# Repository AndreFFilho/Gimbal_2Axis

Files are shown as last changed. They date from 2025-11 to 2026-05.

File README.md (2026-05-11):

# 📷 IoT 2-Axis Gimbal Stabilization System (ESP32)






<p align="center">
  Gimbal Stabilization Demo
</p>

This repository contains the firmware for the embedded system and the supervisory interface for a **2-Axis Gimbal** (Pitch and Roll). The project was developed with a focus on **Real-Time Automation** and **Embedded Systems**, using the **ESP32** microcontroller.

The system combines **Field Oriented Control** (FOC), Sensor Fusion via **Kalman Filter**, and secure IoT communication over **MQTT**.

---

## 📂 Repository Structure

The repository is organized in a modular way to facilitate maintenance and testing:

```text
├── assets/              # PCB Design and Schematics
├── hardware/            # Gerber Files (PCB Manufacturing)
├── components/          # External Libraries (I2Cdev, MPU6050)
├── main/
│   ├── BATERIA/         # ADC Reading and Moving Average Filter
│   ├── BOTAO/           # Interrupt Handling and Debounce
│   ├── BUFFER/          # Circular Buffer (Producer-Consumer)
│   ├── LOGGER/          # Hybrid Logging System (Serial/MQTT)
│   ├── MPU6050/         # Driver Abstraction and Kalman Filter
│   ├── PID/             # Control Algorithm and SimpleFOC
│   ├── WIFI_MQTT/       # Connection Management and IoT Protocol
│   ├── main.c           # System Initialization and Task Orchestration
│   └── mainGlobals.h    # Mutexes, Semaphores and Global Variables
├── .devcontainer/       # Docker Environment Configuration
├── Interface/           # Flet Interface (Python)
└── CMakeLists.txt       # Build Configuration
```

---

## 🌟 Firmware Features

* **Real-Time Control:** Deterministic **PID loop** running at **200Hz (5ms)**, prioritized via FreeRTOS.
* **SimpleFOC:** Vector Control (SVPWM) for Brushless motors (BLDC), ensuring smooth motion.
* **Sensor Fusion:** Implemented via **Kalman Filter**.
* **IoT & MQTT:** Telemetry (Angle/Battery) and remote setpoint reception over MQTT with TLS support.
* **Multitasking:** Architecture based on Tasks, Queues, Mutexes and Semaphores to prevent *race conditions*.
* **Reproducible Environment:** Native support for **Docker (Dev Containers)**.

## 🧠 Technical Challenges & Control Strategy

**Overcoming Sensor Latency:**
Initially, the system relied on the MPU6050’s internal Digital Motion Processor (DMP) to obtain pitch and roll angles. However, the DMP introduced processing delays that restricted the control bandwidth. This latency prevented us from increasing the PID gains without pushing the system into instability, resulting in a sluggish motor response. 

To solve this, we bypassed the DMP entirely. By implementing a custom **Kalman Filter** directly on the raw accelerometer and gyroscope data, we drastically reduced latency and increased the sampling rate. This software solution allowed for higher PID gains, yielding a much faster and more aggressive system response.

**Mechanical Resonance & Structural Flexibility:**
During high-frequency operation, we identified a mechanical limitation. The 3D-printed ABS arms exhibited structural flexibility, essentially acting as a mass-spring (second-order) system. When the motors accelerated rapidly to correct large errors, the arms vibrated. While the control loop was robust enough to stabilize the gimbal, this mechanical resonance lowered the overall margin of stability. This highlighted the crucial relationship between rigid mechanical design and high-frequency control loops.

---

## 🛠️ Hardware and Pinout

The firmware is configured with the **following** pin assignment for the ESP32 (DevKit V1):

* **Microcontroller:** ESP32 (DevKit V1 or similar).
* **Sensors:** MPU6050 (Accelerometer + Gyroscope).
* **Actuators:** 2x Brushless Motors (Gimbal Motors) + 2x Drivers (SimpleFOC Mini v1.0).
* **Power Supply:** Li-Ion Battery 2S (7.4V).
* **Converters:** Buck Mini360 and Boost XL6009.
* **Connections (Default Pinout):**

| Component | ESP32 Pin | Function | Details |
| :--- | :--- | :--- | :--- |
| **I2C Bus** | GPIO 21 (SDA), 22 (SCL) | Communication | MPU6050 Sensor (Address 0x68) |
| **Pitch Motor** | GPIO 19, 18, 17 | PWM (Phases A/B/C) | SimpleFOC Mini v1.0 |
| **Roll Motor** | GPIO 25, 26, 27 | PWM (Phases A/B/C) | SimpleFOC Mini v1.0 |
| **Motor Enable**| GPIO 4 (Pitch), 14 (Roll)| Digital Out | Driver Enable Signal |
| **Battery** | GPIO 34 | Analog In (ADC) | Voltage Divider (2S Monitoring) |
| **Button** | GPIO 33 | Digital In (ISR) | Physical Button with Pull-up |
| **Status LED** | GPIO 32 | Digital Out | Battery Indicator |

### 🖨️ Printed Circuit Board (PCB)

A dedicated PCB was developed to ensure **mechanical robustness** for the Gimbal assembly. The **design includes** onboard voltage regulation and modular connectors.

| Top View | Bottom View |
| :---: | :---: |
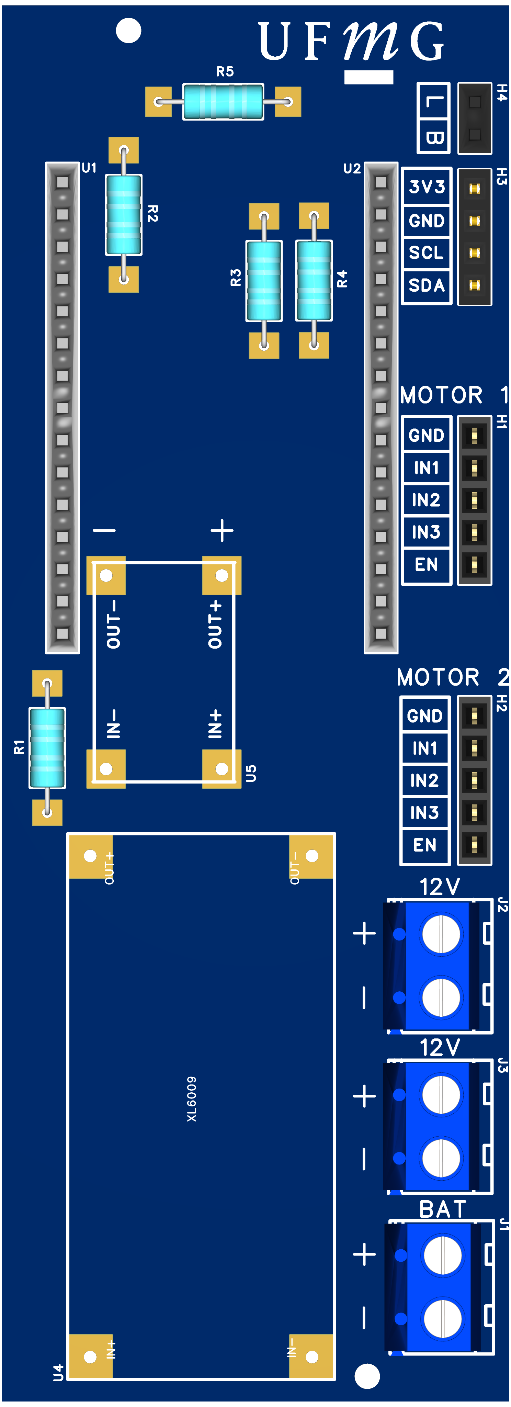
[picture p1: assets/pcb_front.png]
Front View PCB
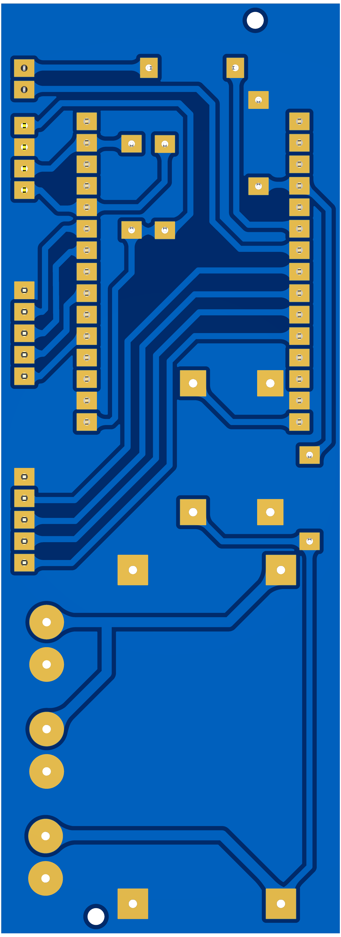
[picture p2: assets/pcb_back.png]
Back View PCB
|  |  |

> **Note:** The PCB was designed using **EasyEDA**. Manufacturing files (Gerbers) can be found in the `hardware/` folder.

## 🚀 Compilation Guide (Firmware)

### Prerequisites
* **ESP-IDF v5.5.1** (Recommended Version).
* ESP32 USB Driver (CP210x or CH340).

### Option A: Docker (Recommended)
This repository includes a `.devcontainer` configuration. If you are using VS Code:
1.  Install the **Dev Containers** extension.
2.  Open the project folder and click on **"Reopen in Container"**.
3.  The environment will be set up automatically with all necessary tools.
4.  Compile:
    ```bash
    idf.py build
    ```

### Option B: Manual Installation (Native)
1.  Install the ESP-IDF v5.5.1.
2.  Download the SimpleFOC dependency:
    ```bash
    idf.py add-dependency "espressif/esp_simplefoc^1.2.1"
    ```
3.  **Critical Configuration (Kernel):**
    * Execute `idf.py menuconfig`.
    * Navigate to `Component config` → `FreeRTOS` → `Kernel`.
    * Change `configTICK_RATE_HZ` to **1000** (1kHz). *This is essential for the main loop (5ms) to run correctly.*

### Network Configuration (Wi-Fi and MQTT)
⚠️ **Warning:** Security credentials are not version-controlled (ignored by git). Please update the following files before compiling: 

1.  **Wi-Fi:** `main/WIFI_MQTT/wifi_sta.c` (SSID and Password).
2.  **MQTT:** `main/WIFI_MQTT/mqtt_esp32.c` (Broker URI, Username and Password).

### Flashing and Monitoring
Connect the ESP32 via USB and run:
```bash
# Replace COMx with your specific port (e.g., COM3 or /dev/ttyUSB0)
idf.py -p COMx flash monitor
```

---

## 🖥️ Desktop Interface

The Graphics User Interface (UI) allows you to visualize telemetry data and send control commands. The Python source code is located in the `Interface/` folder.

### Interface Structure

- **`main.py`**: Entry Point. Initializes Flet and MQTT process.
- **`GUI/app.py`**: Builds the UI (Sliders, Charts, Telemetry Cards).
- **`favoritos.xlsx`**: Local storage for saved positions.
- **`MQTT/`**: Communication Module.
  - `config.py`: Broker and Topic Configurations.
  - `cliente.py`: Paho-MQTT Client with debounce logic.
  - `mqtt_process.py`: Background process to prevent GUI freezing.
  - `mqtt_logger.py`: Utility for saving logs to CSV.

### Running the Interface

**Prerequisites:** Python 3.10+ and `pip`.

1.  Navigate to the interface folder:
    ```bash
    cd Interface
    ```
2.  Create and activate a virtual environment (recommended):
    ```bash
    python -m venv .venv
    # Windows:
    .\.venv\Scripts\activate
    # Linux/Mac:
    source .venv/bin/activate
    ```
3.  Install dependencies:
    ```bash
    pip install -r requirements.txt
    ```
    *(requirements.txt content: `flet`, `paho-mqtt`, `openpyxl`)*

4.  Run the application:
    ```bash
    python main.py
    ```

---

## 👏 Credits and Acknowledgments

This project uses robust open-source tools. Special thanks to the developers of:

* **[SimpleFOC](https://simplefoc.com/)**: Vector Control Library (FOC) for Arduino/ESP32, maintained by Antun Skuric and the community.
* **[I2Cdev / MPU6050](https://github.com/jrowberg/i2cdevlib)**: Jeff Rowberg’s original driver and ports for ESP32 by ElectronicCats.
* **[Flet](https://flet.dev/)**: Python Framework used to build a modern and reactive Desktop Interface.
* **[ESP-IDF](https://docs.espressif.com/projects/esp-idf/en/latest/esp32/)**: Espressif’s Official IoT Development Framework.

## 📝 License and Authors

This project was developed as a requirement for the **Real-Time Automation** and **Embedded Project Design** courses at the **Universidade Federal de Minas Gerais (UFMG)**.

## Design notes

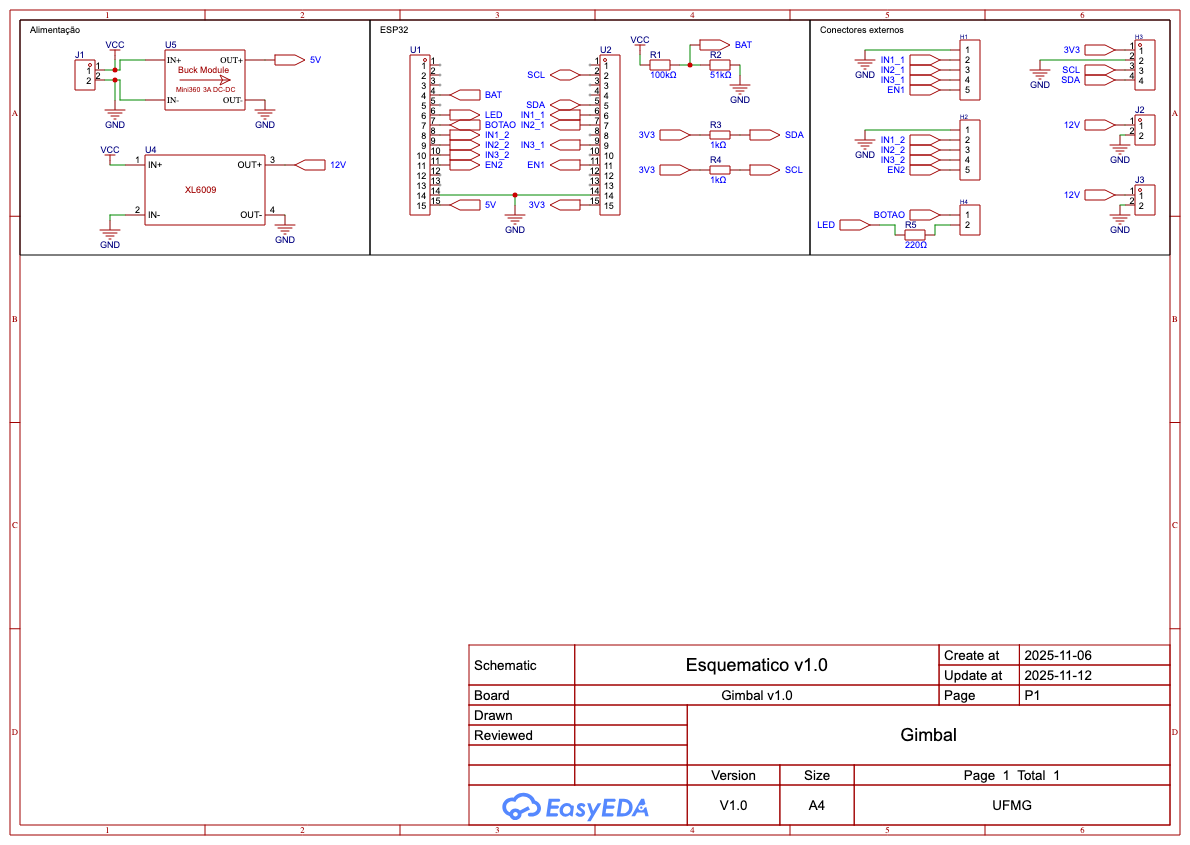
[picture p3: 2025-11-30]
assets/Esquematico.png

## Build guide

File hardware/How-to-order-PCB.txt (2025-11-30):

How to Order PCB

Please refer to:
https://prodocs.easyeda.com/en/pcb/order-order-pcb/index.html

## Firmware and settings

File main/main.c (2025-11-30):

#include <stdio.h>
#include "freertos/FreeRTOS.h"
#include "freertos/task.h"
#include "log_mqtt.h"
#include "esp_err.h"
#include "mainGlobals.h"
#include "SensorMPU6050.h"
#include "ControladorPID.h"
#include "mqtt_esp32.h"
#include "wifi_sta.h"
#include "adc_bateria.h"
#include "botao.h"
#include "BufferTelemetria.h"

// --- Declarações Globais Compartilhadas ---
float pr[2] = {0.0f, 0.0f};             // [pitch, roll]   Ângulos alvo de Pitch e Roll em graus
float pr_medido[2] = {0.0f, 0.0f};      // [pitch, roll]   Ângulos medidos de Pitch e Roll em graus
SemaphoreHandle_t mutex_pr;             // Mutex para proteger o acesso à variável pr
SemaphoreHandle_t mutex_sensor_data;    // Mutex para proteger o acesso à variável pr_medido
SemaphoreHandle_t g_mpu_pronta;         // Semáforo para indicar que o MPU está pronto

void task_mqtt_publish(void *pvParameters) {
    float dados[2];
    while (1) {
        // Aguarda até haver dados no buffer circular
        if (buffer_telemetria_ler(dados, portMAX_DELAY)) {
            mqtt_publish_telemetry(dados[0], dados[1]);
        }
    }
    vTaskDelete(NULL);
}

void app_main(void)
{
    LOGI("MAIN", "Iniciando aplicação...");

    // Inicializa mutex e queue
    mutex_pr = xSemaphoreCreateMutex();
    mutex_sensor_data = xSemaphoreCreateMutex();
    g_mpu_pronta = xSemaphoreCreateBinary();

    const size_t CAPACIDADE_BUFFER_TELEMETRIA = 200;
    if (!buffer_telemetria_iniciar(CAPACIDADE_BUFFER_TELEMETRIA)) {
        LOGE("MAIN", "Falha ao iniciar buffer de telemetria");
    }

    LOGI("MAIN", "Globais (Mutex/Filas) criadas.");

    wifi_init_sta();
    mqtt_start();
    setup_adc();
    botao_init_isr_task();

    xTaskCreatePinnedToCore(task_initI2C, "task_initI2C", 2048, NULL, 10, NULL, 1);
    vTaskDelay(500 / portTICK_PERIOD_MS);
    xTaskCreatePinnedToCore(task_mpu, "task_mpu", 8192, NULL, 10, NULL, 1);
    LOGI("MAIN", "Task MPU criada.");
    xTaskCreatePinnedToCore(task_pid, "task_pid", 4096, NULL, 9, NULL, 1);
    LOGI("MAIN", "Task PID criada.");
    xTaskCreatePinnedToCore(task_mqtt_publish, "task_mqtt_publish", 4096, NULL, 3, NULL, 0);
    LOGI("MAIN", "Task MQTT Publish criada.");
    xTaskCreatePinnedToCore(task_leitura_bateria, "task_leitura_bateria", 2048, NULL, 2, NULL, 0);
    LOGI("MAIN", "Task Leitura Bateria criada.");
}

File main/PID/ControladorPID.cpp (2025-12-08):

// --- Includes Padrão e de Biblioteca ---
#include <stdio.h>
#include <math.h>
#include "freertos/FreeRTOS.h"
#include "freertos/task.h"
#include "driver/ledc.h"
#include "driver/gpio.h"
#include "log_mqtt.h"

// --- Includes das Bibliotecas C++ SimpleFOC ---
#include "esp_simplefoc.h"
#include "ControladorPID.h"
#include "mainGlobals.h"

// --- Definições ---
#define IN1_1 19
#define IN2_1 18
#define IN3_1 17
#define EN1 4
#define IN1_2 25
#define IN2_2 26
#define IN3_2 27
#define EN2 14

const float deadzone = 0.005;
const float MAX_ANGLE = 1.46608f;

#define MAX_INTEGRADOR 30.0f
#define MIN_INTEGRADOR -30.0f
#define D_FILTER_ALPHA 0.2f

// Variáveis Globais
static BLDCMotor motor_pitch = BLDCMotor(7);
static BLDCDriver3PWM driver_pitch = BLDCDriver3PWM(IN1_1, IN2_1, IN3_1, EN1);
static BLDCMotor motor_roll = BLDCMotor(7);
static BLDCDriver3PWM driver_roll = BLDCDriver3PWM(IN1_2, IN2_2, IN3_2, EN2);

// Estrutura PID
typedef struct {
    float kp, ki, kd;
    float integrador;
    float medicao_anterior;
    float derivada_filtrada;
} PID_t;

// Inicializa o controlador PID
void PID_Init(PID_t *pid, float kp, float ki, float kd) {
    pid->kp = kp;
    pid->ki = ki;
    pid->kd = kd;
    pid->integrador = 0.0f;
    pid->medicao_anterior = 0.0f;
    pid->derivada_filtrada = 0.0f;
}

// Calcula a saída do controlador PID
float PID_Compute(PID_t *pid, float erro, float medicao, float dt) {
    if (dt <= 0.0f) return 0.0f;

    // P
    float P = pid->kp * erro;

    // I
    pid->integrador += erro * dt;
    if (pid->integrador > MAX_INTEGRADOR) pid->integrador = MAX_INTEGRADOR;
    else if (pid->integrador < MIN_INTEGRADOR) pid->integrador = MIN_INTEGRADOR;
    float I = pid->ki * pid->integrador;

    // D
    float derivada_raw = -(medicao - pid->medicao_anterior) / dt;
    pid->derivada_filtrada = (D_FILTER_ALPHA * derivada_raw) + (1.0f - D_FILTER_ALPHA) * pid->derivada_filtrada;
    float D = pid->kd * pid->derivada_filtrada;

    pid->medicao_anterior = medicao;
    return P + I + D;
}

// --- Tarefa Principal ---
void task_pid(void *ignore) {
    xSemaphoreTake(g_mpu_pronta, portMAX_DELAY);
    // Espera um pouco para o sensor estabilizar totalmente
    vTaskDelay(pdMS_TO_TICKS(500)); 

    LOGI("PID", "Configurando Motores...");
    
    // Configuração do driver BLDC
    driver_pitch.voltage_power_supply = 12;
    driver_roll.voltage_power_supply = 12;
    driver_pitch.voltage_limit = 11;
    driver_roll.voltage_limit = 11;
    driver_pitch.init(0);
    driver_roll.init(1);

    // Configuração do motor BLDC
    motor_pitch.linkDriver(&driver_pitch);
    motor_roll.linkDriver(&driver_roll);
    motor_pitch.velocity_limit = 20;
    motor_roll.velocity_limit = 20;
    motor_pitch.voltage_limit = 3;
    motor_roll.voltage_limit = 3;
    motor_pitch.current_limit = 0.5f;
    motor_roll.current_limit = 0.5f;

    // Inicialização dos motores
    motor_pitch.controller = MotionControlType::velocity_openloop;
    motor_roll.controller = MotionControlType::velocity_openloop;
    motor_pitch.init();
    motor_roll.init();

    // Inicialização do PID
    PID_t pid_pitch, pid_roll;
    PID_Init(&pid_pitch, 8.0f, 0.01f, 1.0f);
    PID_Init(&pid_roll,  8.0f, 0.01f, 1.2f);

    const float dt = 0.001f;     // 1ms de tempo fixo para o PID
    float erro_pitch, erro_roll;
    float setpoint_pitch, setpoint_roll;
    float medicao_pitch_rad, medicao_roll_rad;

    // Variáveis da Rampa
    static float setpoint_suave_pitch = 0.0f;
    static float setpoint_suave_roll = 0.0f;
    // Diminuí a velocidade da rampa para garantir torque (0.001 rad/ms = 1 rad/s)
    float max_step = 0.001f; 

    // Lê onde o gimbal está AGORA para começar a rampa dali
    xSemaphoreTake(mutex_sensor_data, portMAX_DELAY);
    setpoint_suave_pitch = pr_medido[0]; 
    setpoint_suave_roll  = pr_medido[1];
    
    // Também inicializa o histórico do PID para evitar derivada louca no primeiro loop
    pid_pitch.medicao_anterior = pr_medido[0];
    pid_roll.medicao_anterior  = pr_medido[1];
    xSemaphoreGive(mutex_sensor_data);

    const TickType_t xFrequency = pdMS_TO_TICKS(1); // 1ms
    TickType_t xLastWakeTime = xTaskGetTickCount();

    LOGI("PID", "Iniciando loop de cálculo PID...");
    
    while (1) {
        // 1. ESPERA ATÉ O PRÓXIMO CICLO DE 1ms
        vTaskDelayUntil(&xLastWakeTime, xFrequency);
        
        // 2. PEGA O SETPOINT ATUALIZADO
		xSemaphoreTake(mutex_pr, portMAX_DELAY);
		setpoint_pitch = pr[0] * M_PI / 180.0f;	// Converte para radianos
		setpoint_roll = pr[1] * M_PI / 180.0f;	// Converte para radianos
		xSemaphoreGive(mutex_pr);

        // 3. APLICA LIMITE DE SEGURANÇA
        // Aplica um limite de segurança ao setpoint para evitar Gimbal Lock
        setpoint_pitch = fmaxf(-MAX_ANGLE, fminf(MAX_ANGLE, setpoint_pitch)); // Limita Pitch
        setpoint_roll = fmaxf(-MAX_ANGLE, fminf(MAX_ANGLE, setpoint_roll)); // Limita Roll

        // 4. PEGA A ÚLTIMA MEDIÇÃO DO SENSOR
        xSemaphoreTake(mutex_sensor_data, portMAX_DELAY);
        medicao_pitch_rad = pr_medido[0]; // Já está em radianos
        medicao_roll_rad  = pr_medido[1]; // Já está em radianos
        xSemaphoreGive(mutex_sensor_data);

        // 5. RAMPA SUAVE
        float diferenca_p = setpoint_pitch - setpoint_suave_pitch;
        if (fabs(diferenca_p) > max_step) {
            if (diferenca_p > 0) setpoint_suave_pitch += max_step;
            else setpoint_suave_pitch -= max_step;
        } else {
            setpoint_suave_pitch = setpoint_pitch;
        }

        float diferenca_r = setpoint_roll - setpoint_suave_roll;
        if (fabs(diferenca_r) > max_step) {
            if (diferenca_r > 0) setpoint_suave_roll += max_step;
            else setpoint_suave_roll -= max_step;
        } else {
            setpoint_suave_roll = setpoint_roll;
        }

        // 6. CALCULA O ERRO
        erro_pitch = setpoint_suave_pitch - medicao_pitch_rad;  // Erro de Pitch em radianos
        erro_roll  = setpoint_suave_roll  - medicao_roll_rad;   // Erro de Roll em radianos

        // 7. APLICA DEADZONE
        if (fabsf(erro_pitch) < deadzone) erro_pitch = 0.0f;
        if (fabsf(erro_roll) < deadzone) erro_roll = 0.0f;

        // 8. CALCULA O PID COM O 'dt' FIXO
        float output_pitch = PID_Compute(&pid_pitch, erro_pitch, medicao_pitch_rad, dt);
        float output_roll  = PID_Compute(&pid_roll,  erro_roll, medicao_roll_rad, dt);

        // 9. ATUALIZA A SAÍDA PARA O MOTOR
        motor_pitch.move(-output_pitch);
        motor_roll.move(output_roll);
    }
}

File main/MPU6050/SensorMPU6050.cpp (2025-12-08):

// --- Includes Padrão e de Biblioteca ---
#include <driver/i2c.h>
#include "log_mqtt.h"
#include <esp_err.h>
#include <math.h>
#include "freertos/FreeRTOS.h"
#include "freertos/task.h"
#include "BufferTelemetria.h"
#include "esp_timer.h"
#include "esp_rom_sys.h"

// --- Includes das Bibliotecas C++ do MPU6050 ---
#include "MPU6050.h"
#include "sdkconfig.h"
#include "mainGlobals.h"
#include "SensorMPU6050.h"

// --- Pinos I2C sensor MPU6050 ---
#define PIN_SDA 21
#define PIN_SCL 22

// --- Filtro de Kalman ---
class KalmanFilter {
public:
    float angle = 0.0f;
    float bias  = 0.0f;
    float P[2][2] = {{0,0},{0,0}};

    float Q_angle = 0.001f;
    float Q_bias  = 0.005f;
    float R_measure = 0.03f; 

    void predict(float gyro_rate, float dt) {
        angle += dt * (gyro_rate - bias);
        P[0][0] += dt * (dt*P[1][1] - P[0][1] - P[1][0] + Q_angle);
        P[0][1] -= dt * P[1][1];
        P[1][0] -= dt * P[1][1];
        P[1][1] += Q_bias * dt;
    }

    void update(float measured_angle) {
        float y = measured_angle - angle;
        float S = P[0][0] + R_measure;

        float K0 = P[0][0] / S;
        float K1 = P[1][0] / S;

        angle += K0 * y;
        bias  += K1 * y;

        float P00_temp = P[0][0];
        float P01_temp = P[0][1];

        P[0][0] -= K0 * P00_temp;
        P[0][1] -= K0 * P01_temp;
        P[1][0] -= K1 * P00_temp;
        P[1][1] -= K1 * P01_temp;
    }
};

static KalmanFilter kalmanPitch;
static KalmanFilter kalmanRoll;

// Task de inicialização do barramento I2C
void task_initI2C(void *ignore) {
    i2c_config_t conf = {};
    conf.mode = I2C_MODE_MASTER;
    conf.sda_io_num = (gpio_num_t)PIN_SDA;
    conf.scl_io_num = (gpio_num_t)PIN_SCL;
    conf.sda_pullup_en = GPIO_PULLUP_ENABLE;
    conf.scl_pullup_en = GPIO_PULLUP_ENABLE;
    conf.master.clk_speed = 400000; // 400kHz para velocidade
    ESP_ERROR_CHECK(i2c_param_config(I2C_NUM_0, &conf));
    ESP_ERROR_CHECK(i2c_driver_install(I2C_NUM_0, I2C_MODE_MASTER, 0, 0, 0));
    vTaskDelete(NULL);
}

// Task de inicialização do barramento I2C
void task_mpu(void *) {
    MPU6050 mpu;
    // Inicializa comunicação com o MPU6050
    mpu.initialize();

    if (!mpu.testConnection()) {
        printf("ERRO: MPU6050 não conectado!\n");
        vTaskDelete(NULL);
    }
    printf("MPU6050 conectado.\n");

	// Calibrações de Offset pré-definidas
    mpu.setXAccelOffset(-3678); mpu.setYAccelOffset(-2954); mpu.setZAccelOffset(1392);

	// Escala Padrão +/- 2g (1g = 16384)
    mpu.setFullScaleAccelRange(MPU6050_ACCEL_FS_2);
    mpu.setFullScaleGyroRange(MPU6050_GYRO_FS_500);

    printf("Calibrando Giroscópio...\n");
    mpu.CalibrateGyro(20);
    printf("Calibração concluída.\n");

    // Leitura Inicial para definir ângulos iniciais
    int32_t sum_ax = 0, sum_ay = 0, sum_az = 0;
    int32_t sum_gx = 0, sum_gy = 0;
    int16_t ax, ay, az, gx, gy, gz;

    for (int i=0; i<100; i++) {
        mpu.getMotion6(&ax, &ay, &az, &gx, &gy, &gz);
        sum_ax += ax; sum_ay += ay; sum_az += az;
        sum_gx += gx; sum_gy += gy;
        esp_rom_delay_us(1000);
    }

    float avg_ax = sum_ax / 100.0f;
    float avg_ay = sum_ay / 100.0f;
    float avg_az = sum_az / 100.0f;
    float avg_gx = sum_gx / 100.0f;
    float avg_gy = sum_gy / 100.0f;

    // Pitch (Y): atan2(-ax, sqrt(ay² + az²))
    float init_pitch = atan2(-avg_ax, sqrt(avg_ay*avg_ay + avg_az*avg_az));

    // Roll (X): atan2(ay, az)
    float init_roll  = atan2(avg_ay, avg_az);

    // Inicializa Filtros de Kalman com os valores iniciais
    kalmanRoll.angle  = init_roll;
    kalmanPitch.angle = init_pitch;
    kalmanRoll.bias  = (avg_gx / 131.0f) * (M_PI/180.0f);
    kalmanPitch.bias = (avg_gy / 131.0f) * (M_PI/180.0f);

    // Indica que o MPU está pronto
    xSemaphoreGive(g_mpu_pronta);

    // Tempo de loop da task do MPU6050
    int64_t last_time = esp_timer_get_time();
    int telemetry_counter = 0;

    while(1) {
        int64_t now = esp_timer_get_time();

        // Delta time em segundos
        float dt = (now - last_time) / 1000000.0f;
        last_time = now;

        // Lê dados brutos do sensor
        mpu.getMotion6(&ax, &ay, &az, &gx, &gy, &gz);

        // Converte para unidades físicas
        float gxr = (gx/65.0f)*(M_PI/180.0f);
        float gyr = (gy/65.0f)*(M_PI/180.0f);

        // Pitch (Eixo X do sensor, rotação sobre Y)
        float acc_p = atan2((float)-ax, sqrt((float)ay*ay + (float)az*az));

        // Roll (Eixo Y do sensor, rotação sobre X) 
        float acc_r = atan2((float)ay, (float)az);

        // Atualiza Filtros de Kalman
        kalmanRoll.predict(gxr, dt);
        kalmanRoll.update(acc_r);

        kalmanPitch.predict(gyr, dt);
        kalmanPitch.update(acc_p);

        // Atualiza variáveis globais de ângulo
        xSemaphoreTake(mutex_sensor_data, portMAX_DELAY);
        pr_medido[0] = kalmanPitch.angle;
        pr_medido[1] = kalmanRoll.angle;
        xSemaphoreGive(mutex_sensor_data);

        // Envia o ângulo para a interface MQTT
        telemetry_counter++;
        if (telemetry_counter >= 50) {  // 20Hz Telemetria
            telemetry_counter = 0;      // Reseta o contador
            // Envia o ângulo atual (em graus) para a fila de telemetria
			// Envia os dados para o buffer circular de telemetria
            float tel[2];
            tel[0] = kalmanPitch.angle * 180/M_PI;
            tel[1] = kalmanRoll.angle * 180/M_PI;
            buffer_telemetria_gravar(tel, 0);            
        }
		vTaskDelay(pdMS_TO_TICKS(1));
    }
}

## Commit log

2025-11-30 feat: lançamento inicial do firmware ESP32 e documentação do sistema
    - Firmware: Adicionado laço de controle PID (200Hz), integração SimpleFOC e driver MPU6050 DMP.
    - IoT: Implementada comunicação MQTT/TLS e arquitetura de tarefas (FreeRTOS).
    - Hardware: Adicionados arquivos Gerber da PCB, esquemáticos e diagramas de conexão.
    - Config: Adicionado suporte a DevContainer (Docker) para ambiente reprodutível.
    Nota: A Interface Desktop (Python/Flet) será adicionada em um commit posterior.
    [Drill_PTH_Through.DRL, Gerber_BoardOutlineLayer.GKO, Gerber_BottomLayer.GBL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]
2025-11-30 docs: adicionando seção de creditos e licença
2025-11-30 Upload da Interface
    Interface gráfica em Python para controle de um gimbal de dois eixos via MQTT sobre TLS, usando Flet. A aplicação envia comandos de pitch e roll para o ESP32, exibe telemetria (incluindo tensão de ba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
    [favoritos.xlsx]
2025-12-08 Refactor: Substitui DMP por Filtro de Kalman e aprimora estabilidade do PID
    Mudanças principais:
    Sensor (MPU6050):
    - Remoção completa da biblioteca DMP (Digital Motion Processor) para reduzir latência.
    - Implementação de Filtro de Kalman customizado para fusão de Acelerômetro e Giroscópio.
    - Aplicação de offsets de calibração "hardcoded" para correção precisa do eixo Z.
    - Otimização da leitura I2C para rodar a 1kHz.
    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
2025-12-08 docs: atualiza README para refletir a troca do DMP pelo Filtro de Kalman
2026-05-11 Expand README with technical challenges and solutions
    Added section on technical challenges and control strategy, detailing solutions for sensor latency and mechanical resonance.

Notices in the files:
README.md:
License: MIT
